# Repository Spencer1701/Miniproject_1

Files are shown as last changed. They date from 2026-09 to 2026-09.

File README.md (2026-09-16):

# Miniproject_1
First Miniproject for Senior Design

A USB-powered MicroPython meeting timer using a XIAO ESP32-S3, a stepper-driven
clock hand, two buttons, and an RGB LED. Presets are 15, 20, 25, and 30 minutes.
An enclosure is optional for this team, which has no mechanical engineering members.

Use [code/meeting_timer.py](code/meeting_timer.py). See the
[operating instructions](docs/operating-instructions.md),
[state chart](docs/state-chart.md), and [references](docs/references.md).
The printed compact clock face and hand set is in
[mechanical/stl/mini_clock_face_and_hands.stl](mechanical/stl/mini_clock_face_and_hands.stl).
See the [KiCad schematic](electrical/schematic/README.md) and
[wiring photo](wiring/wiring.jpg). Current verification and remaining submission
items are in [firmware notes](docs/firmware.md).

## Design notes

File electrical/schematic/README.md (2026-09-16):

# Schematic

The team supplied the [version 2 PDF](KiCAD%20schematic%20V2.pdf),
[editable KiCad source](Mini-project.kicad_sch), and
[change notes](schematic_changelog.md). The earlier [version 1 image](KiCAD%20schematic.png)
is retained for reference. TODO: resolve the physical checks noted in the
change notes and [wiring reference](../wiring-reference.md).

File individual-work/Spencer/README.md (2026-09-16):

# Individual Contributions: Spencer

## 1. Demo Video
- **Editing tool:** used iMovie for timelapse to demonstrate under time limit and exported 

## 2. Project Summary

- **Tool used:** drafted in Claude and relied and edited by me 
- **Source materials referenced:** the KiCad schematic (`schematic.pdf`),
  the quick user guide, and a photo/state-machine diagram of the device provided by my team 
- **Process:** [Owen and DJ
  from the schematic and firmware, another wrote the usage
  walkthrough from the user guide, then it was merged and reviewed by
  Me

## 3. GitHub and Group Organization

- **Repository structure:** I was uncharge of organizing the mini project GitHub and structuring it 

## 4. Division of Work

| Team member | Responsibilities |
|---|---|
| [Owen] | [Code, 3D CAD, troubleshooting] |
| [DJ] | [Code ] |
| [Ayin] | [Wiring ] |
| [Vinny] | [Schematics and Wiring] || [Vinny] | [Schematics and Wiring] || [Vinny] | [Schematics and Wiring] || [Vinny] | [Schematics and Wiring] || [Vinny] | [Schematics and Wiring] || [Vinny] | [Schematics and Wiring] |
And I did everything else highlighted in this doc 
I helped coordinate people with what they wanted to do as well as manage the teams. In addition I also oversaw tasks such as wiring and schematics for example 

*(Adjust roles/names as needed — this table can also note overlap,
e.g. "everyone contributed to testing and debugging.")*

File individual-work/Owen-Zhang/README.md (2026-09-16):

# Owen Zhang — ECE 463 Miniproject 1

My work focused on the MicroPython meeting-timer software, hardware integration
and testing, and the clock-face/hand and enclosure design iterations.

| Work | Files |
| --- | --- |
| Final MicroPython program | [meeting_timer.py](code/meeting_timer.py): timer presets, button controls, hand calibration, stepper motion, and RGB PWM |
| Printed compact design | [Clock face and hand set](3d-printing/mini_clock_face_and_hands.stl): square dial, LED opening, and three alternative hand fits |
| Earlier enclosure designs | [Flat lid](3d-printing/timer_lid_flat_v2.stl) and [base with small parts](3d-printing/timer_base_and_parts_v2.stl): prototype designs, not the selected print job |

I ran the physical button, RGB, and motor checks and reported the observations
used to refine the final configuration. The code uses real 15/20/25/30-minute
presets, motor direction `-1`, and RGB GPIO order `(8, 9, 7)`.

Supporting material stays in the shared repository: [software tests](../../tests/README.md),
[state chart](../../docs/state-chart.md), [operating instructions](../../docs/operating-instructions.md),
and [verification notes](../../docs/firmware.md). The final KiCad schematic and
circuit photo were supplied by teammates.

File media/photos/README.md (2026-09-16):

# Photos

The team-supplied circuit photo is [wiring.jpg](../../wiring/wiring.jpg).

TODO: add clear photos of the completed timer, including its clock hand and
circuit. Use actual device photos rather than CAD renders.

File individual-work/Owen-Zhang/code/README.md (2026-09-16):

# Code

[meeting_timer.py](meeting_timer.py) is the final standalone MicroPython program.
Open it in Thonny and press F5, or save it on the device as `main.py` for startup.
See the shared [operating instructions](../../../docs/operating-instructions.md)
and [tests](../../../tests/README.md).

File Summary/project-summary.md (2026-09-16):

# Meeting Timer — Project Summary

**Course:** ECE 463

## 1. Device Description

The Meeting Timer is a countdown clock built around a Seeed
XIAO ESP32-S3 microcontroller. A 28BYJ-48 stepper motor, driven through
an L293D H-bridge driver, rotates a physical clock hand around a printed
dial face labeled with 5-minute increments from 0 to 30 (with 0 and 30
sharing a single mark). An onboard RGB LED communicates the device's
current state (calibrating, selecting a duration, running, paused, or
finished), and two pushbuttons — **SET** and **RUN** — are used to zero
the hand, pick a preset duration, and start/pause/reset the countdown.

Four presets are supported: **15, 20, 25, and 30 minutes** (no 10-minute
preset in the current firmware).

### Core hardware
| Component | Role |
|---|---|
| XIAO ESP32-S3 (U1) | Main controller |
| L293D H-bridge driver (U2) | Drives the 28BYJ-48 stepper motor |
| 28BYJ-48 stepper motor (M1) | Rotates the clock hand |
| RGB LED (D1) with 220 Ω resistors | Status indication |
| SET button (SW1), RUN button (SW2) | User input |

## 2. Photos

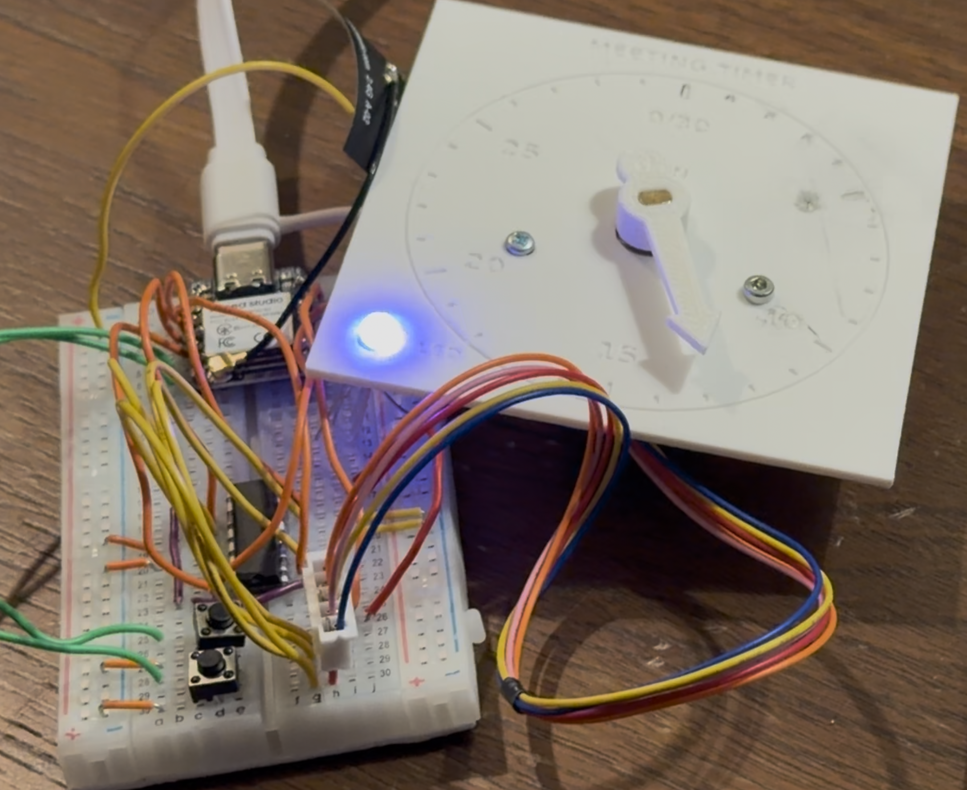
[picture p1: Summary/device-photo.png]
Meeting Timer device


*The assembled breadboard circuit — XIAO ESP32-S3, breadboard wiring, an
RGB LED lit blue, and the 3D-printed dial/hand assembly with the stepper
motor connected via a 5-wire cable.*

## 3. How to Use

**Button positions** (as originally laid out, XIAO on the left): SET is
the button closer to the XIAO; RUN is farther away. A **tap** is a
quick press-and-release; a **hold** is about 1.5 seconds.

### Step 1 — Power on and zero the hand
1. Connect USB with both buttons released. (If needed, start the
   program in Thonny with F5.)
2. While the LED pulses **purple**, tap **SET** to move the hand
   forward (hold to keep moving), or tap **RUN** to move it backward.
3. Align the hand with the 0/30 mark, release the buttons, and wait
   for it to stop. Hold **RUN** for 1.5 seconds, then release to
   confirm zero and enter selection mode.

### Step 2 — Select a duration and start
After a fresh power-up and zero calibration, 15 minutes is selected by
default.

| Duration | Extra SET taps | Blue pulses/group | Start |
|---|---|---|---|
| 15 min | 0 | 1 | Tap RUN once |
| 20 min | 1 | 2 | Tap RUN once |
| 25 min | 2 | 3 | Tap RUN once |
| 30 min | 3 | 4 | Tap RUN once |

Wait for the hand to stop moving before tapping RUN. SET cycles
15 → 20 → 25 → 30 → 15. Count the blue LED pulses (in groups with a
2-second gap) to confirm the current selection. SET only changes the
selection before starting or after the timer has finished.

### Step 3 — Read the LED
| LED behavior | Meaning |
|---|---|
| Purple pulses | Setting the hand's zero position |
| 1–4 blue pulses + gap | Selecting 15/20/25/30 minutes |
| Green pulses | Running, more than 5 minutes remain |
| Red pulses (counting down) | Running, 5 minutes or less remain |
| Repeating blue, no gap | Paused |
| Red pulses, hand at zero | Finished (continues until acknowledged) |

There is no buzzer — the timer is read visually.

### Step 4 — Pause, restart, or reset
- **Pause/resume:** tap RUN to pause; tap RUN again (once settled) to resume.
- **Cancel/reload:** hold RUN for 1.5 seconds, wait for the hand to
  reposition, then tap RUN to restart.
- **After completion:** tap RUN to reload, wait, then tap RUN again to
  start — or tap SET to pick the next preset.
- **Recalibrate:** outside purple mode, hold SET for 1.5 seconds to
  repeat zero-setting (the selected preset is retained).
- **Turn off:** unplug USB. Every power-up requires a fresh zero
  calibration; an interrupted countdown is not saved.

## 4. Video of Device in Operation

 [Meeting Timer in operation](https://drive.google.com/file/d/1wPqdghsCuRPDjGa9a-UBrjxjEYcKuRwZ/view?usp=share_link)

## 5. References to Source Materials

- XIAO ESP32-S3 hardware documentation (Seeed Studio)
- L293D quadruple half-H driver datasheet (Texas Instruments)
- 28BYJ-48 stepper motor datasheet/reference
- CircuitPython/Thonny toolchain used for firmware development
- `code/meeting_timer.py` — project firmware (`QUICK_TEST = False` for
  normal operation; accelerated test mode uses shorter durations)

## 6. Project Support Documents

### Schematic
See attached schematic: **`schematic.pdf`** (KiCad, "Miniproject schematic",
Rev. —, Sheet 1/1).

Summary of connections:
- **XIAO ESP32-S3 (U1):** GPIO7/8/9 drive the RGB LED channels (each
  through a 220 Ω resistor); additional GPIOs connect to SET (SW1) and
  RUN (SW2) buttons and to the L293D driver inputs.
- **L293D Driver (U2):** Receives logic-level control signals from the
  XIAO and drives the 28BYJ-48 stepper motor (M1) through connector J1.
- **RGB LED (D1):** Common status indicator, driven from three GPIOs
  through current-limiting resistors.
- **Power/Ground:** Shared 5V/3V3/GND rails across the XIAO, LED, and
  motor driver.

### Firmware State Machine

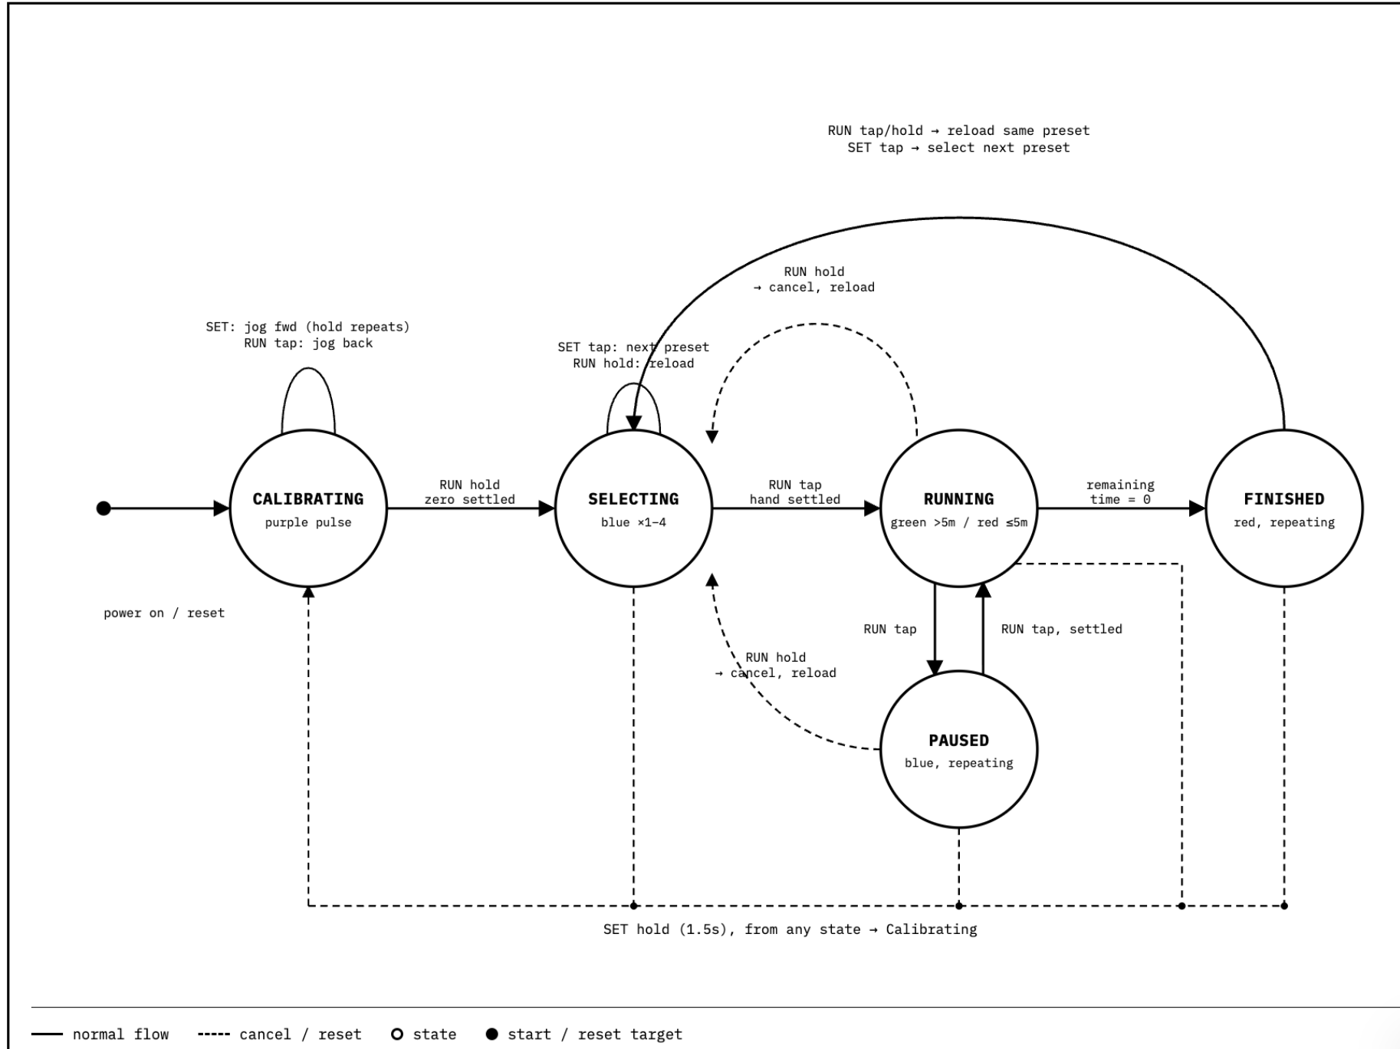
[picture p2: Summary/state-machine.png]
Meeting Timer state machine


The firmware moves through five states:

| State | LED indication | Description |
|---|---|---|
| **Calibrating** | Purple pulse | Entered on power-on/reset. SET jogs the hand forward (hold repeats); RUN tap jogs it back. Holding RUN for 1.5 s once the hand is zeroed and settled advances to Selecting. |
| **Selecting** | Blue ×1–4 | SET tap cycles through the four presets (15→20→25→30→15). RUN tap, once the hand has settled, starts the countdown (→ Running). |
| **Running** | Green (>5 min left) / Red (≤5 min left) | Counts down. RUN tap pauses (→ Paused). Reaching zero remaining time moves to Finished. |
| **Paused** | Blue, repeating | RUN tap resumes Running once settled. |
| **Finished** | Red, repeating | Terminal state until acknowledged. |

**Global reset:** holding **SET for 1.5 seconds from any state** cancels
and returns to Calibrating.

**Cancel/reload:** holding **RUN for 1.5 seconds** from Selecting, Running,
or Paused cancels the current countdown and reloads the same preset back
into Selecting. From Finished, a RUN tap or hold reloads the same preset;
a SET tap instead selects the next preset.

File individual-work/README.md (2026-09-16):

# Individual work

[Owen Zhang — software, integration, documentation, and mechanical design iterations](Owen-Zhang/README.md).

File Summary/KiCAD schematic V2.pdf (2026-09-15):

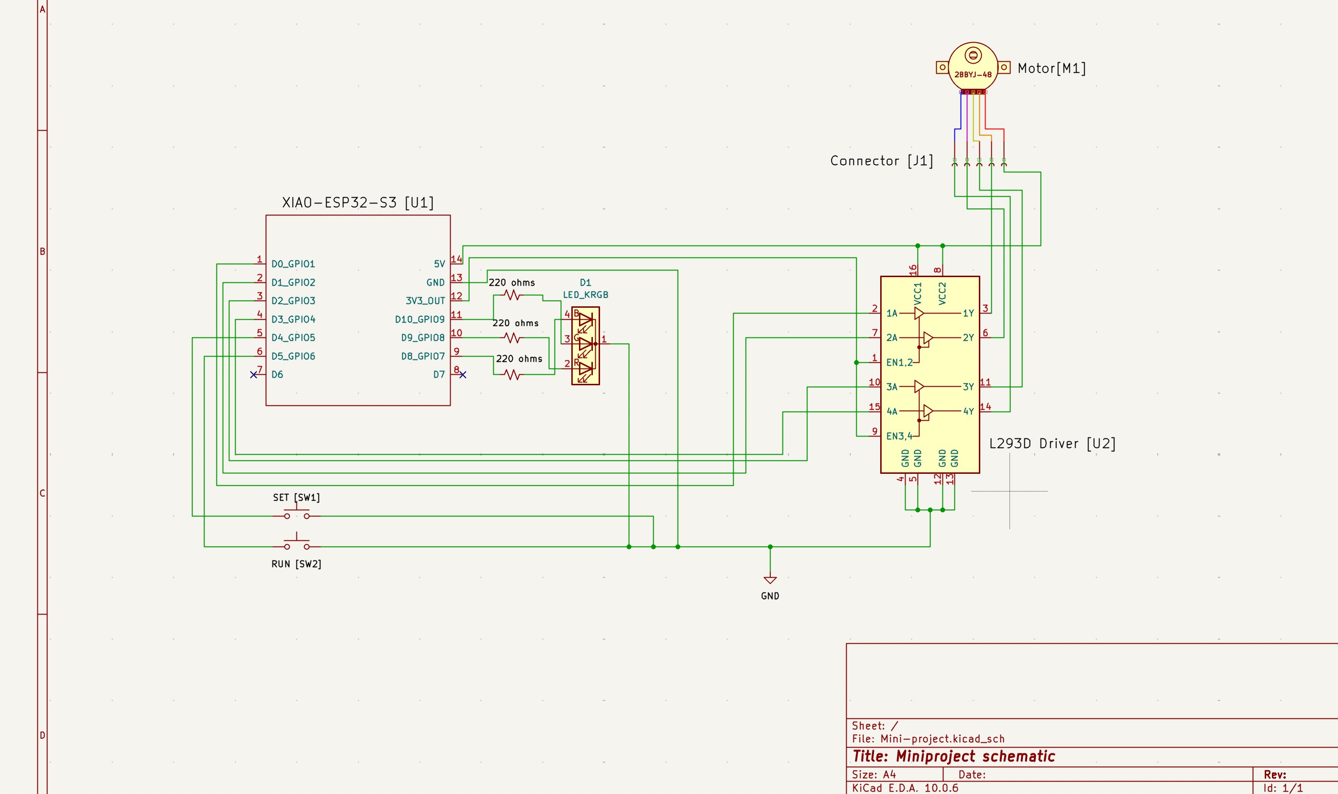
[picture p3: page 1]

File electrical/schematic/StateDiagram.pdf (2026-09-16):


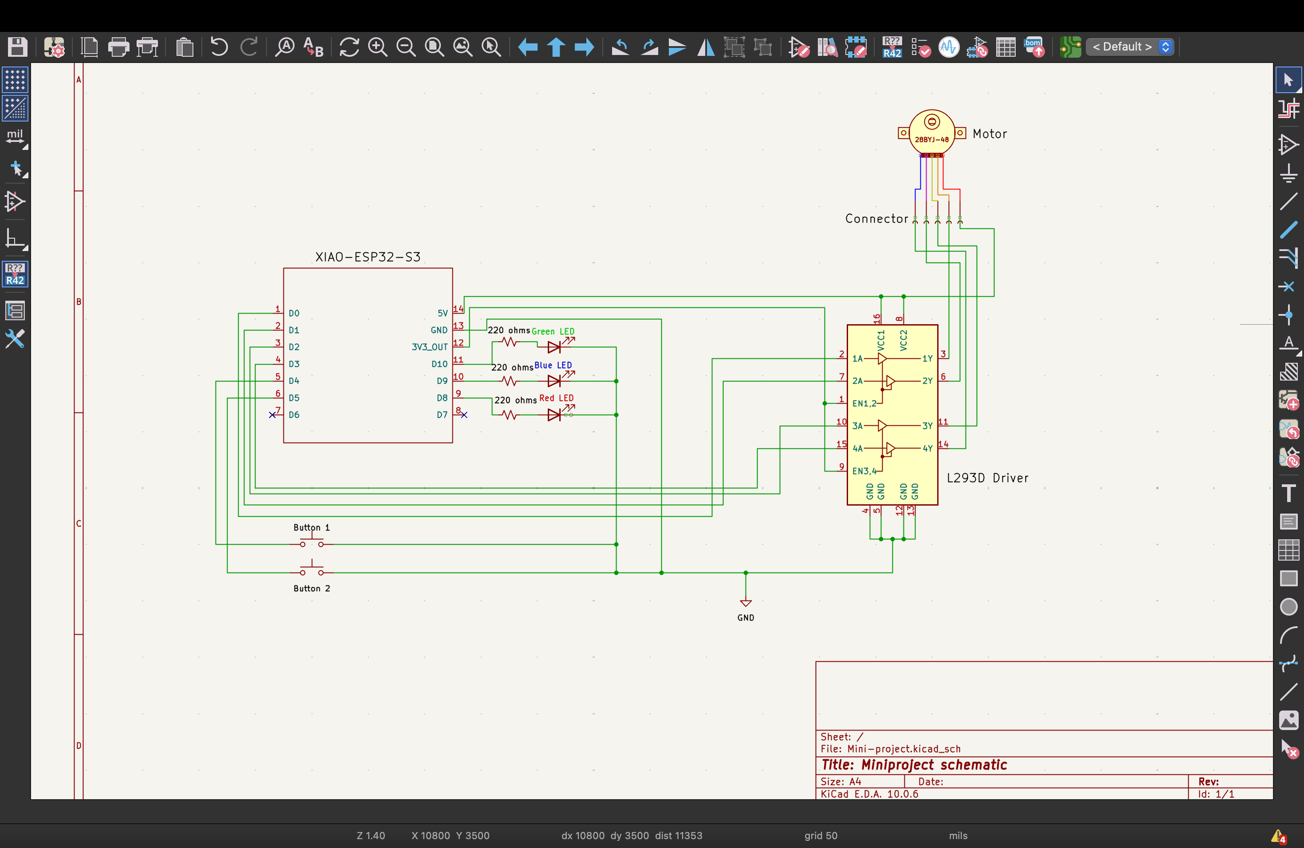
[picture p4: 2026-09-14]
electrical/schematic/KiCAD schematic.png

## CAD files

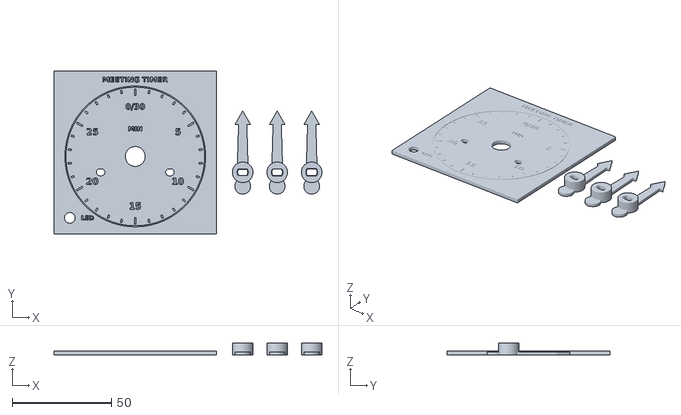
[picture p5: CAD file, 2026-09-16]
individual-work/Owen-Zhang/3d-printing/mini_clock_face_and_hands.stl
135.2 x 82.0 x 6.00

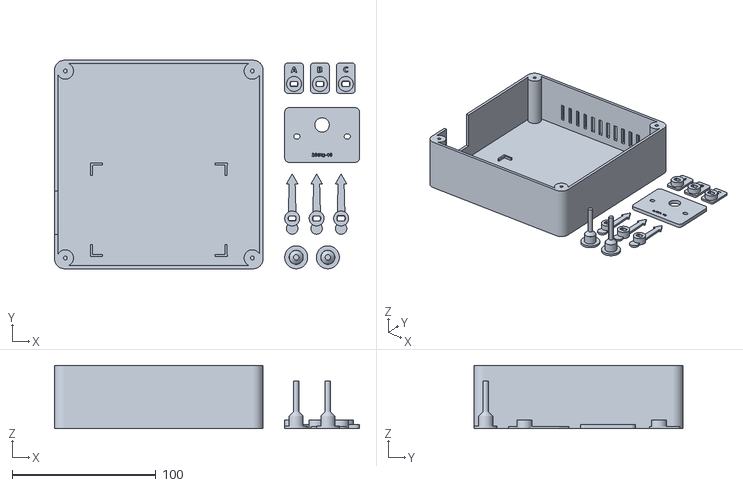
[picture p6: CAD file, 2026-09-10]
individual-work/Owen-Zhang/3d-printing/timer_base_and_parts_v2.stl
212.0 x 145.0 x 44.0

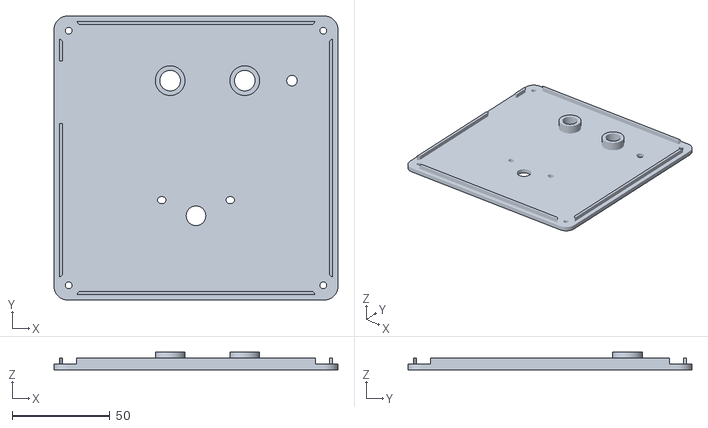
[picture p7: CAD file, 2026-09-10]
individual-work/Owen-Zhang/3d-printing/timer_lid_flat_v2.stl
145.0 x 145.0 x 9.00

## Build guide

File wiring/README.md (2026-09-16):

# Wiring photo

[wiring.jpg](wiring.jpg) is the team-supplied circuit photo.
Use the [schematic](../electrical/schematic/README.md) and
[wiring reference](../electrical/wiring-reference.md) for connections.

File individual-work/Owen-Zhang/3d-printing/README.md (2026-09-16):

# 3D printing files

**Printed design:** [mini_clock_face_and_hands.stl](mini_clock_face_and_hands.stl).
The combined file contains the compact 82 × 82 × 2 mm clock face with an LED
opening and three alternative shaft-fit hands. The full layout is
135.2 × 82 × 6 mm. Install one hand. Reprint at 100% scale in millimetres,
flat as supplied, using a slicer profile for the actual printer.

[timer_lid_flat_v2.stl](timer_lid_flat_v2.stl) and
[timer_base_and_parts_v2.stl](timer_base_and_parts_v2.stl) are earlier optional
full-enclosure prototypes retained to show the design iterations. Their
physical fit has not been verified.

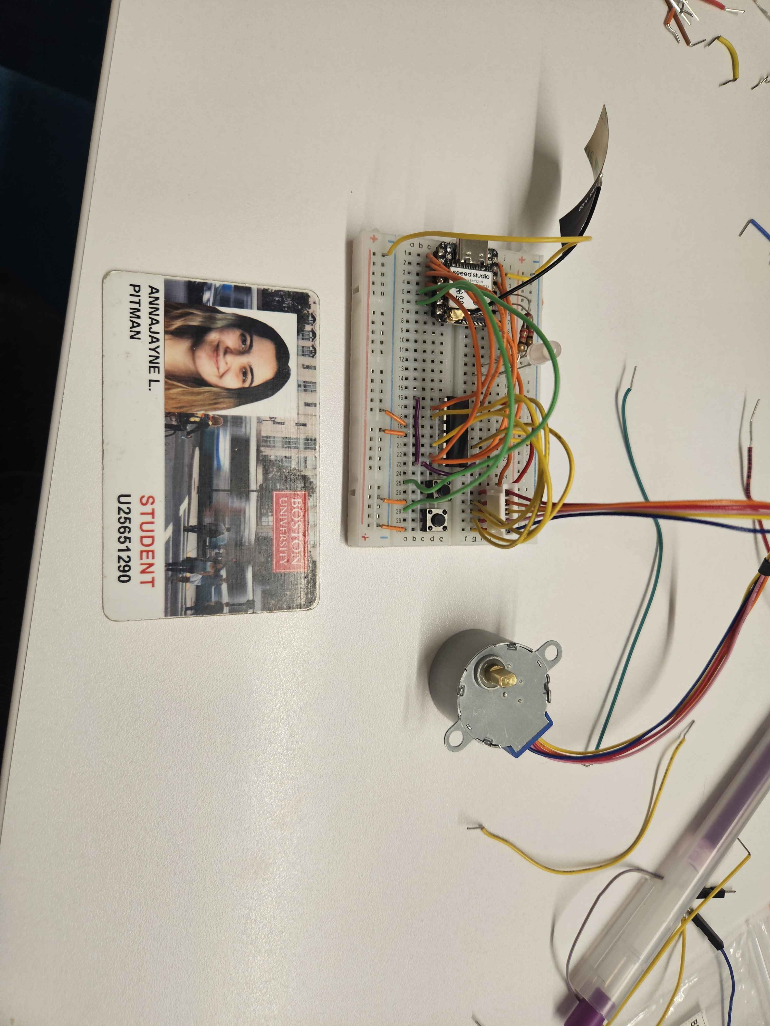
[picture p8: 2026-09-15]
wiring/wiring.jpg

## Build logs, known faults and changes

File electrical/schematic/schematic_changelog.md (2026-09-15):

# Schematic Changelog — Meeting Timer Mini-Project

Documents changes made to `Mini-project.kicad_sch` after the initial (v1) version, and why each was made.

## v1 → v2 Corrections

### 1. RGB LED representation — switched to a single common-cathode symbol
- **Before:** The schematic modeled the RGB LED as three separate Device:LED symbols (D1/D2/D3), requiring their cathodes to be manually netted together. D2's cathode originally had no connection at all — that color channel's circuit was open as drawn.
- **After:** Replaced with a single Device:LED_KRGB symbol (one designator, matching the team's "D1" convention) — a standard common-cathode RGB LED part with three anode pins (one per color) and one shared cathode pin built directly into the part.
- **Why:** wiring-reference.md identifies this as one physical common-cathode RGB LED package, not three independent LEDs. Using the dedicated library symbol represents that accurately, removes the need to manually tie three separate cathode nets together, and resolves the earlier D1/D2/D3-vs-single-"D1" designator mismatch.

### 2. Button 1 (SW1) ground connection
- **Before:** SW1 pin 2 was tied to the LED cathode net instead of ground.
- **After:** SW1 pin 2 now connects to GND, matching how SW2 (Button 2) was already wired.
- **Why:** `wiring-reference.md`: *"an unpressed switch reads HIGH and pressing it connects the input to GND"* — both switches need their own dedicated GND return.

### 3. Red/Blue LED GPIO assignment swap
- **Before:** R3 (Red LED resistor) → GPIO7 (D8); R2 (Blue LED resistor) → GPIO8 (D9) — matched the generic course example table.
- **After:** Swapped so Red → GPIO8 (D9), Blue → GPIO7 (D8).
- **Why:** `wiring-reference.md`'s hookup table is sourced from the team's actual tested, working firmware [commit 376af36], which uses the opposite assignment from the course's generic example. The tested build takes precedence over the generic reference.

## Documentation additions (not circuit changes)

- Added net labels (GPIO, SET, RUN, U1, U2 , J1 etc) for schematic readability.

## Still open
- Noted 0.1µF bypass capacitors at VCC1/VCC2 as **proposed, not yet installed** — pending physical confirmation, per TI's datasheet guidance (p.13) and `wiring-reference.md`'s TODO.

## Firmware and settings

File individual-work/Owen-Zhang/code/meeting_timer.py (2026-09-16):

"""Standalone MicroPython meeting timer for the team's final breadboard.

Open this one file in Thonny and press F5. No supporting files need uploading.
QUICK_TEST=True uses 30/40/50/60 SECOND runs for the 15/20/25/30 preset labels.
Set QUICK_TEST=False for the actual 15/20/25/30 MINUTE durations.

At startup, purple means calibration: SET jogs forward, a RUN tap jogs back.
Hold RUN for 1.5 seconds to accept the current position as 0/30. Wait about
27 seconds for the initial half-turn to the 15-minute position. Tap RUN to
start; tap again to pause/resume. SET cycles presets while selecting. Hold
RUN to cancel/reset or hold SET to recalibrate. Short actions occur on release.

Green pulses while more than five minutes remain, then red for the final five
minutes of every preset (last 10 seconds in quick mode). Blue indicates selection
or pause. Both buttons held together are ignored until both are released.

Current wiring: motor D0-D3/GPIO1-4, SET D4/GPIO5, RUN D5/GPIO6; RGB red GPIO8,
green GPIO9, blue GPIO7, active-high, with individual series resistors. L293D
pins 8/16 and motor red common use USB 5V, with common ground. Enables 1/9 stay
HIGH; D7 is unused. Ctrl+C stops phase commands and PWM, but fixed enables do
not disconnect the windings. Unplug USB after testing. Low-power operation and
physical timer accuracy are not established by this bench build.

Generated from repository logic, with a fixed-enable driver option and the
team's observed phase order/speed. Position is estimated; no encoder is fitted.
"""

QUICK_TEST = False  # Explicit accelerated test; False selects real-minute timing.
FIRMWARE_REVISION = "2026-09-15-direction-fix"

class BenchSettings:
    """Hardware and timing configuration for the XIAO ESP32-S3 meeting timer.

    GPIO numbers below are ESP32 numbers, not the D-labels printed on the XIAO.
    Bench settings match the team's reported button, RGB, and motor checks.
    The complete timer and its power consumption still need physical testing.
    """

    # This bench profile uses the wiring already exercised by the diagnostics.
    WIRING_CONFIRMED = True
    # Active-high RGB operation confirmed by the team's two-cycle bench test.
    # False = common cathode to GND; True = common anode to 3V3.
    RGB_COMMON_ANODE = False

    # L293D inputs 1A/2A/3A/4A: pins 2/7/10/15; XIAO D0/D1/D2/D3.
    # Output wires respectively: orange/pink/yellow/blue; motor red common to 5V.
    MOTOR_GPIOS = (1, 2, 3, 4)
    # A cyclic order for the nominal 28BYJ-48: orange, yellow, pink, blue.
    # Case A at 25 ms: user reported a smooth approximate half-turn and return.
    MOTOR_PHASE_ORDER = (0, 2, 1, 3)
    MOTOR_ACTIVE_LEVEL = 0  # Common at +5V: the selected output must sink current.
    # Existing wiring ties L293D enables HIGH; None means D7 is never configured.
    # This profile does not provide true high-impedance coil release.
    MOTOR_ENABLE_GPIO = None
    SET_GPIO = 5  # D4, normally-open switch to GND; internal pull-up.
    RUN_GPIO = 6  # D5, normally-open switch to GND; also the light-sleep wake pin.
    # Final pin check: GPIO7 blue, GPIO8 red, GPIO9 green; no channel swap.
    RGB_GPIOS = (8, 9, 7)  # R/G/B = D9/D10/D8, each through its own 220-ohm resistor.

    PRESET_MINUTES = (15, 20, 25, 30)
    DIAL_MINUTES = 30  # Matches the printed face: 0/30 at the top, 15 at the bottom.
    MINUTE_MS = 2000 if QUICK_TEST else 60000
    WARNING_REMAINING_MS = 5 * MINUTE_MS
    # Nominal full/wave steps, NOT the 4096 half-step convention.
    # TODO: measure an output revolution and adjust for your motor's gear ratio.
    STEPS_PER_REVOLUTION = 2048
    # Reverse the original phase direction for the team's front-facing dial.
    # Positive logical motion follows increasing marks clockwise; the countdown
    # moves counterclockwise. Re-zero the hand after changing this setting.
    MOTOR_DIRECTION = -1
    STEP_INTERVAL_MS = 25  # Conservative starting rate; no blocking motor loops.
    COIL_SETTLE_MS = 100  # Dwell before removing phase commands; fixed enables remain active.
    CALIBRATION_JOG_STEPS = 8
    CALIBRATION_REPEAT_MS = 160

    DEBOUNCE_MS = 30
    LONG_PRESS_MS = 1500
    PWM_FREQUENCY_HZ = 1000
    PULSE_PERIOD_MS = 1000
    MAX_LED_DUTY = 32768  # 16-bit duty limit; resistors still limit peak LED current.
    LED_UPDATE_MS = 20
    LOOP_SLEEP_MS = 2
    LIGHT_SLEEP_ENABLED = False  # Fixed-enable bench wiring; keep USB/Thonny responsive.
    IDLE_SLEEP_MS = 60 * 1000

    def validate(self):
        """Reject unsafe or inconsistent configuration before creating GPIOs."""
        if not self.WIRING_CONFIRMED:
            raise ValueError('Check docs/firmware.md, then set WIRING_CONFIRMED=True')
        if type(self.RGB_COMMON_ANODE) is not bool:
            raise ValueError('Set RGB_COMMON_ANODE to True or False after checking LED')
        pins = self.MOTOR_GPIOS + self.RGB_GPIOS + (self.SET_GPIO, self.RUN_GPIO)
        if self.MOTOR_ENABLE_GPIO is not None:
            pins += (self.MOTOR_ENABLE_GPIO,)
        if self.MOTOR_ENABLE_GPIO is None and self.LIGHT_SLEEP_ENABLED:
            raise ValueError('Fixed enables cannot provide the coil-off sleep mode')
        exposed = (1, 2, 3, 4, 5, 6, 7, 8, 9, 43, 44)
        if len(set(pins)) != len(pins) or any((pin not in exposed for pin in pins)):
            raise ValueError('Use unique exposed XIAO GPIOs; D0 is GPIO1, not GPIO0')
        if len(self.MOTOR_GPIOS) != 4 or len(self.RGB_GPIOS) != 3:
            raise ValueError('Exactly four motor inputs and three RGB channels required')
        if tuple(sorted(self.MOTOR_PHASE_ORDER)) != (0, 1, 2, 3):
            raise ValueError('MOTOR_PHASE_ORDER must be a permutation of 0,1,2,3')
        if self.MOTOR_ACTIVE_LEVEL not in (0, 1) or self.MOTOR_DIRECTION not in (-1, 1):
            raise ValueError('Invalid motor polarity or direction')
        if not isinstance(self.STEPS_PER_REVOLUTION, int) or self.STEPS_PER_REVOLUTION < 4:
            raise ValueError('STEPS_PER_REVOLUTION must be a positive calibrated count')
        if self.PRESET_MINUTES != (15, 20, 25, 30) or self.DIAL_MINUTES != 30:
            raise ValueError('Keep the course presets and the 30-minute printed dial')
        intervals = (self.STEP_INTERVAL_MS, self.COIL_SETTLE_MS, self.DEBOUNCE_MS, self.LONG_PRESS_MS, self.CALIBRATION_REPEAT_MS, self.PWM_FREQUENCY_HZ, self.PULSE_PERIOD_MS, self.LED_UPDATE_MS, self.LOOP_SLEEP_MS, self.IDLE_SLEEP_MS)
        if any((value <= 0 for value in intervals)):
            raise ValueError('Timing constants must be positive')
        if self.LONG_PRESS_MS <= self.DEBOUNCE_MS or not 0 < self.MAX_LED_DUTY <= 65535:
            raise ValueError('Invalid button timing or LED duty limit')
        if not 0 < self.CALIBRATION_JOG_STEPS < self.STEPS_PER_REVOLUTION // 2:
            raise ValueError('Calibration jog must be less than half a revolution')
        if self.LIGHT_SLEEP_ENABLED and self.RUN_GPIO not in (1, 2, 3, 4, 5, 6, 7, 8, 9):
            raise ValueError('Light-sleep wake must use an exposed RTC-capable GPIO')


config = BenchSettings()


class WaveStepper:
    """Drive a four-phase unipolar motor through a noninverting L293D.

    An enable GPIO provides high-impedance release when connected. With
    enable=None, release() only removes active phase commands; outputs remain
    driven and residual winding current can flow through the L293D.
    Only the selected input has active_level; all others are inactive. With
    the red motor common at +5V, active_level MUST be 0 (current sinking).
    Position is an open-loop estimate, not a sensor reading.
    """

    def __init__(
        self,
        pins,
        enable,
        phase_order,
        active_level,
        direction,
        steps_per_rev,
        interval_ms,
        settle_ms,
        ticks_diff,
        now,
    ):
        self.pins = pins
        self.enable = enable
        self.order = phase_order
        self.active = active_level
        self.direction = direction
        self.steps_per_rev = steps_per_rev
        self.interval_ms = interval_ms
        self.settle_ms = settle_ms
        self.diff = ticks_diff
        self.position = self.target = 0
        self.phase = 0
        self.last_step_at = now
        self.energized = False
        self.release()

    def release(self):
        """Remove phase commands, disabling outputs only when an enable GPIO exists."""
        if self.enable is not None:
            self.enable.value(0)
        for pin in self.pins:
            pin.value(1 - self.active)
        self.energized = False

    def _energize(self, now):
        # Remove the previous active command before selecting the next winding.
        if self.enable is not None:
            self.enable.value(0)
        for pin in self.pins:
            pin.value(1 - self.active)
        self.pins[self.order[self.phase]].value(self.active)
        if self.enable is not None:
            self.enable.value(1)
        self.energized = True
        self.last_step_at = now

    def align(self, now):
        """Seat the rotor at a known phase before the user sets the hand zero."""
        self.target = self.position
        self._energize(now)

    def set_target(self, position):
        """Request a modulo position; motion proceeds via update()."""
        self.target = position % self.steps_per_rev

    def stop(self):
        """Cancel queued motion without discarding the estimated position."""
        self.target = self.position
        self.release()

    def mark_zero(self):
        """Accept a user-confirmed physical zero only when the rotor is settled."""
        if not self.is_settled():
            raise ValueError("Wait for motor motion to finish before setting zero")
        self.position = self.target = 0

    def is_settled(self):
        """True once all requested steps and the final coil dwell are complete."""
        return self.position == self.target and not self.energized

    def update(self, now):
        """Issue at most one step; never burst missed steps after a loop delay."""
        elapsed = self.diff(now, self.last_step_at)
        if self.position == self.target:
            if self.energized and elapsed >= self.settle_ms:
                self.release()
            return
        if elapsed < self.interval_ms:
            return
        delta = (self.target - self.position) % self.steps_per_rev
        step = 1 if delta <= self.steps_per_rev // 2 else -1
        self.phase = (self.phase + step * self.direction) % 4
        self._energize(now)
        self.position = (self.position + step) % self.steps_per_rev


class RgbLed:
    """Translate logical brightness into PWM, including common-anode inversion."""

    def __init__(self, channels, common_anode):
        self.channels = channels
        self.common_anode = common_anode

    def write(self, rgb):
        """Set three duties in [0, 65535]; a logical zero always means off."""
        for channel, duty in zip(self.channels, rgb):
            duty = max(0, min(65535, int(duty)))
            channel.duty_u16(65535 - duty if self.common_anode else duty)

    def off(self):
        """Turn off all three colours without allocating new PWM channels."""
        self.write((0, 0, 0))


CALIBRATING = "calibrating"
SELECTING = "selecting"
RUNNING = "running"
PAUSED = "paused"
FINISHED = "finished"
SHORT = "short"
LONG = "long"


class Button:
    """Debounce an active-low switch; emit short on release or long once.

    A switch held during boot/wake is ignored until released. A long press
    never also emits a short press, preventing an unintended second action.
    """

    def __init__(self, debounce_ms, long_ms, ticks_diff, now, pressed=False):
        self.debounce_ms = debounce_ms
        self.long_ms = long_ms
        self.diff = ticks_diff
        self.reset(now, pressed)

    def reset(self, now, pressed):
        """Consume any held switch, including the press that woke the board."""
        self.raw = self.pressed = bool(pressed)
        self.changed_at = self.pressed_at = now
        self.armed = not pressed
        self.long_sent = False

    def update(self, pressed, now):
        """Return SHORT, LONG, or None after processing one sampled level."""
        pressed = bool(pressed)
        if pressed != self.raw:
            self.raw = pressed
            self.changed_at = now
        if (
            self.raw != self.pressed
            and self.diff(now, self.changed_at) >= self.debounce_ms
        ):
            self.pressed = self.raw
            if self.pressed:
                self.pressed_at = now
                self.long_sent = False
            else:
                # Decide duration here too: a late poll must not misclassify
                # an entire long press as short just because its hold was missed.
                held_ms = self.diff(self.changed_at, self.pressed_at)
                event = None
                if self.armed and not self.long_sent:
                    event = LONG if held_ms >= self.long_ms else SHORT
                self.armed = True
                return event
        if (
            self.pressed
            and self.raw
            and self.armed
            and not self.long_sent
            and self.diff(now, self.pressed_at) >= self.long_ms
        ):
            self.long_sent = True
            return LONG
        return None


class MeetingTimer:
    """Finite-state countdown with no dependence on motor speed or loop rate."""

    def __init__(self, presets_ms, dial_ms, steps_per_rev, ticks_diff, now):
        self.presets = tuple(presets_ms)
        if not self.presets or min(self.presets) <= 0 or max(self.presets) > dial_ms:
            raise ValueError("Presets must fit the positive dial duration")
        self.dial_ms = dial_ms
        self.steps_per_rev = steps_per_rev
        self.diff = ticks_diff
        self.selected = 0
        self.state = CALIBRATING
        self.remaining_ms = self.presets[0]
        self.state_elapsed_ms = 0
        self.last_tick = now

    def transition(self, state):
        """Change state and restart its LED animation phase."""
        self.state = state
        self.state_elapsed_ms = 0

    def update(self, now):
        """Account for elapsed real time, including late loop iterations."""
        elapsed = self.diff(now, self.last_tick)
        if elapsed < 0:
            raise ValueError(
                "Clock moved backward or was not serviced within half a wrap"
            )
        self.last_tick = now
        self.state_elapsed_ms += elapsed
        if self.state == RUNNING:
            self.remaining_ms = max(0, self.remaining_ms - elapsed)
            if self.remaining_ms == 0:
                self.transition(FINISHED)

    def reset(self):
        """Cancel/rearm the selected duration without forgetting the hand zero."""
        self.remaining_ms = self.presets[self.selected]
        self.transition(SELECTING)

    def select_next(self):
        """Cycle presets only while selecting or after completion."""
        if self.state in (SELECTING, FINISHED):
            self.selected = (self.selected + 1) % len(self.presets)
            self.reset()

    def run_button(self, motor_ready):
        """Start/resume only after positioning; pause or acknowledge otherwise."""
        if self.state in (SELECTING, PAUSED) and motor_ready:
            self.transition(RUNNING)
        elif self.state == RUNNING:
            self.transition(PAUSED)
        elif self.state == FINISHED:
            self.reset()

    def target_steps(self):
        """Map remaining time to the fixed dial, rounded to the nearest step.

        Zero and 30 minutes share a physical angle. Modulo positioning avoids
        an unnecessary full revolution when selecting the 30-minute preset.
        """
        rounded = (
            self.remaining_ms * self.steps_per_rev + self.dial_ms // 2
        ) // self.dial_ms
        return rounded % self.steps_per_rev


def indicator_color(timer, warning_ms):
    """Return the commanded color, independent of the PWM fade's brightness.

    This is also reported in Thonny to distinguish time/dial errors from a
    swapped LED connection. It describes the command, not a sensor reading.
    """
    if timer.state == CALIBRATING:
        return "purple"
    if timer.state in (SELECTING, PAUSED):
        return "blue"
    if timer.state == FINISHED or timer.remaining_ms <= warning_ms:
        return "red"
    return "green"


def indicator(timer, period_ms, max_duty, warning_ms):
    """Return logical R/G/B 16-bit brightness; driver handles LED polarity."""
    age = timer.state_elapsed_ms
    phase = age % period_ms
    duty = max_duty * (period_ms - abs(2 * phase - period_ms)) // period_ms
    if timer.state == SELECTING:
        # 1/2/3/4 blue pulses identify 15/20/25/30, followed by a two-second gap.
        pulses = timer.selected + 1
        if age % ((pulses + 2) * period_ms) >= pulses * period_ms:
            duty = 0
    color = indicator_color(timer, warning_ms)
    if color == "purple":
        return duty, 0, duty
    if color == "blue":
        return 0, 0, duty
    if color == "red":
        return duty, 0, 0
    return 0, duty, 0
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

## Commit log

2026-09-10 Implement MicroPython meeting timer with tested controls and hardware setup guide
2026-09-10 Add separate flat lid and remaining parts STL print plates
    [timer_base_and_parts_v2.stl, timer_lid_flat_v2.stl]
2026-09-13 Add standalone timer for tested breadboard wiring
2026-09-13 Document current timer operation and submission folders
2026-09-14 Electrical schematic version 1
    Created a detailed schematic on KiCAD to accurately represent electrical layout.
    [Mini-project.kicad_sch]
2026-09-14 electrical schematic version 1
    Created KiCAD schematic to accurately represent electrical schematic (PNG image)
2026-09-15 schematic v1-> v2 log
    Changes made to version 1 of uploaded schematic along with other documentations pending/finished.
2026-09-15 electrical schematic version 2 PDF
    implemented Changes documented in schematic_changelog.md
2026-09-15 electrical schematic version 2 (KiCAD file)
    implemented changes documented in schematic_changelog.md
    [Mini-project.kicad_sch]
2026-09-15 photo of completed wiring
2026-09-16 Finalize standalone timer and compact clock print
    [mini_clock_face_and_hands.stl]
2026-09-16 Add Owen Zhang individual project work
    [mini_clock_face_and_hands.stl, timer_base_and_parts_v2.stl, timer_lid_flat_v2.stl]
2026-09-16 Simplify Owen individual work to code and print files
    [mini_clock_face_and_hands.stl, timer_base_and_parts_v2.stl, timer_lid_flat_v2.stl]
